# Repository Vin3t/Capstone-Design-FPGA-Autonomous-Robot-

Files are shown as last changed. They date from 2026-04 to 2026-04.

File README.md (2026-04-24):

Autonomous indoor service robots require real-time perception and navigation while maintaining low power consumption for extended operation. Conventional robotic platforms commonly rely on GPU-based systems, such as the NVIDIA Jetson Nano, which provide high computational performance but suffer from significant energy demands. This paper addresses the challenge of achieving efficient real-time processing under constrained power budgets by proposing an FPGA-based autonomous service robot architecture.

The proposed system integrates a Nexys A7 FPGA with a Raspberry Pi 4 to perform real-time perception, mapping, and navigation using LiDAR and stereo vision data. A discretized grid map is constructed on the FPGA, enabling efficient execution of the A* pathfinding algorithm and obstacle avoidance in dynamic indoor environments. Classical edge detection techniques are also implemented to enhance real-time environmental awareness.

The novelty of this work lies in the use of FPGA-based parallel processing to offload computationally intensive navigation tasks, an architecture designed to significantly improve energy efficiency compared to traditional GPU-based solutions. Additionally, the system provides a modular hardware–software co-design framework that supports real-time operation with reduced power consumption.

This work demonstrates a practical and scalable approach for autonomous robotics. Crucially, it establishes the methodological and physical foundation for future quantitative comparisons between FPGA and GPU architectures in mobile robotic applications, with implications for healthcare logistics, office automation, and indoor delivery systems.

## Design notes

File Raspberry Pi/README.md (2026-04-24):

# Raspberry Pi Subsystem

This directory contains the high-level software for the Raspberry Pi, which serves as the central user interface and communication hub for the autonomous service robot. The system handles manual motor control via a PlayStation 4 controller and provides a touchscreen graphical user interface for setting navigation goals and transmitting map data to the Nexys A7 FPGA.

## File Overview

* **`ps4_motor_control.py`**: A manual drive script that uses the Pygame library to read inputs from a connected PS4 controller. It maps the joystick axes to motor speeds and sends CRC16-validated packet commands to a RoboClaw motor controller over UART.
* **`robot_gui.py`**: A Tkinter touchscreen application. It displays a 20x20 navigation grid, manages simulated LiDAR obstacle mapping, captures user goal inputs, and handles bidirectional UART communication with the FPGA for hardware-accelerated A* pathfinding.

## Hardware Requirements

* **Raspberry Pi**  + **Touchscreen display recommended**
* **PS4 DualShock Controller** (Connected via USB)
* **RoboClaw Motor Controller** (Address configured to `128`)
* **Nexys A7 FPGA** (Connected via UART for pathfinding)

## System Setup and Dependencies

Before executing the scripts, ensure the Raspberry Pi's hardware UART is enabled and the serial console is disabled. 

1. Open the Raspberry Pi configuration tool in the terminal:
   ```bash
   sudo raspi-config

2. Navigate to Interface Options -> Serial Port.

3. Select No when asked if a login shell should be accessible over serial.

4. Select Yes when asked if the hardware serial port should be enabled.

5. Reboot the Raspberry Pi.

## Python Dependencies
Install the required libraries using pip:
   '''bash
      pip install pygame pyserial pillow numpy

## Instructions
1. Manual PS4 Control (ps4_motor_control.py)
Ensure the PS4 controller is paired to the Raspberry Pi. The script maps the left and right vertical joystick axes to independent tank-drive motor speeds.

    ```bash
        python3 ps4_motor_control.py

Left Stick (Vertical): Controls Motor 1 (Forward/Backward)

Right Stick (Vertical): Controls Motor 2 (Forward/Backward)

PS Button: Exits the script and safely halts the motors.

2. Autonomous Navigation GUI (robot_gui.py)
Run the GUI within the Raspberry Pi desktop environment.

   python3 robot_gui.py

## GUI Workflow:

Load LiDAR: Generates a map of obstacles (currently simulated for testing purposes).

Set Goal: Tap an empty cell on the 20x20 grid to mark the destination.

SEND & RUN: Transmits the 404-byte payload to the FPGA.

Unlock: Once the FPGA reports a successful arrival (0xBB), the unlock button becomes active, allowing the user to release the cargo.

## FPGA UART Protocol Specification
The robot_gui.py script communicates with the Nexys A7 FPGA using a strict 404-byte UART packet operating at 115200 baud. The FPGA automatically triggers the A* search on the rising edge of the final received map byte.

Transmitted Packet (Raspberry Pi -> FPGA)

Byte Index          Description             Value Range
0                   Start Row               0 - 19
1                   Start Column            0 - 19
2                   Goal Row                0 - 19
3                   Goal Column             0 - 19
4 to 403            Obstacle Map (Row)      0x00 (Free), 0x01 (Obstacle)

Status Replies (FPGA -> Raspberry Pi)
The GUI runs a background thread that polls for 1-byte status updates from the FPGA:

Byte Received           Meaning             System Action
0xAA                    Path Found          Updates the GUI status; motors engage.
0xFF                    No Path Exists      Prompts the user to replan the goal.
0xBB                    Arrived at Target   Navigation completes; enables the delivery lock release.

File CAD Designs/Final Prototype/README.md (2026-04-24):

Pololu: 37d gearmotor-50-70-encoder used as a reference for the motor mounting design ().
Pololu: Pololu wheels 90x10mm ().
Pololu: Motor Shaft mount (connects to the pololu wheel) [].

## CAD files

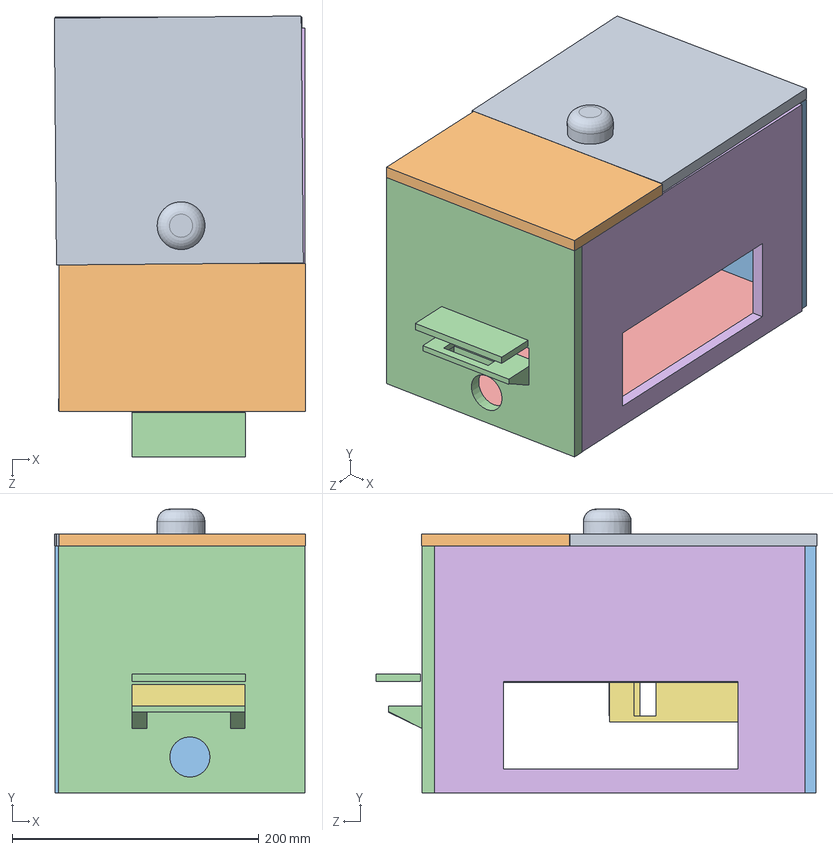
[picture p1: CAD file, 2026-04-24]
CAD Designs/Initial Prototype/robot_assem.SLDASM
203.6 x 229.9 x 357.3 mm
robot_middle_panel
robot_side_parts
robot_base
robot_front_panel
robot_back_panel
robot_lidar_panel
robot_top_hatch

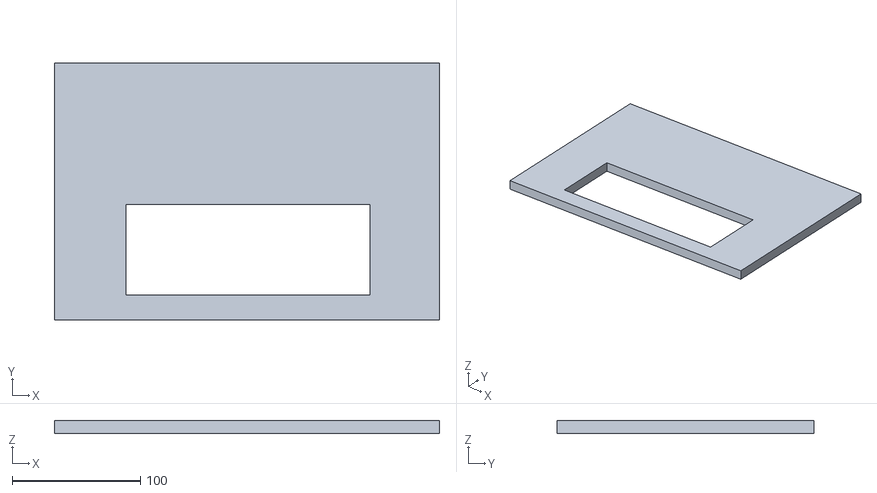
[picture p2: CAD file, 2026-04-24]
CAD Designs/Final Prototype/robot_side_partsv2.STL
300.0 x 200.0 x 10.0

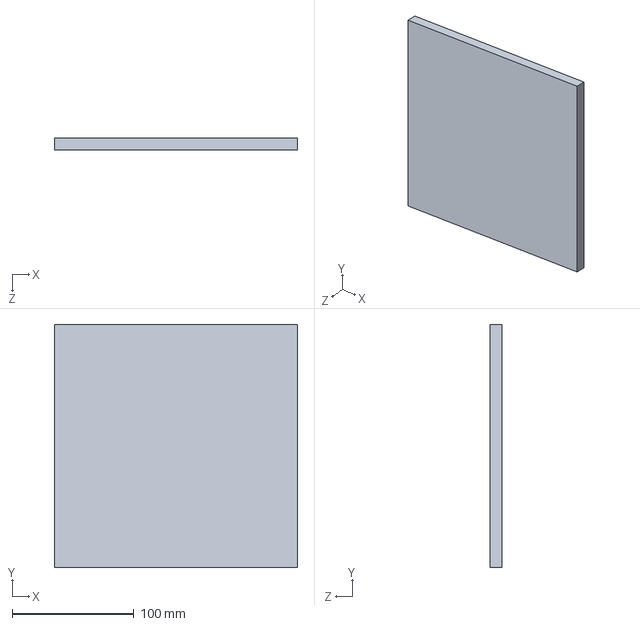
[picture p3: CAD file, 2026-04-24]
CAD Designs/Initial Prototype/robot_back_panel.SLDPRT
200.0 x 200.0 x 10.0 mm

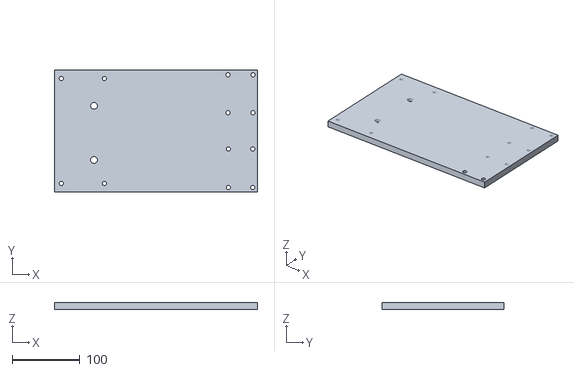
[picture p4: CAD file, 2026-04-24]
CAD Designs/Final Prototype/robot_basev2.STL
300.0 x 180.0 x 10.0

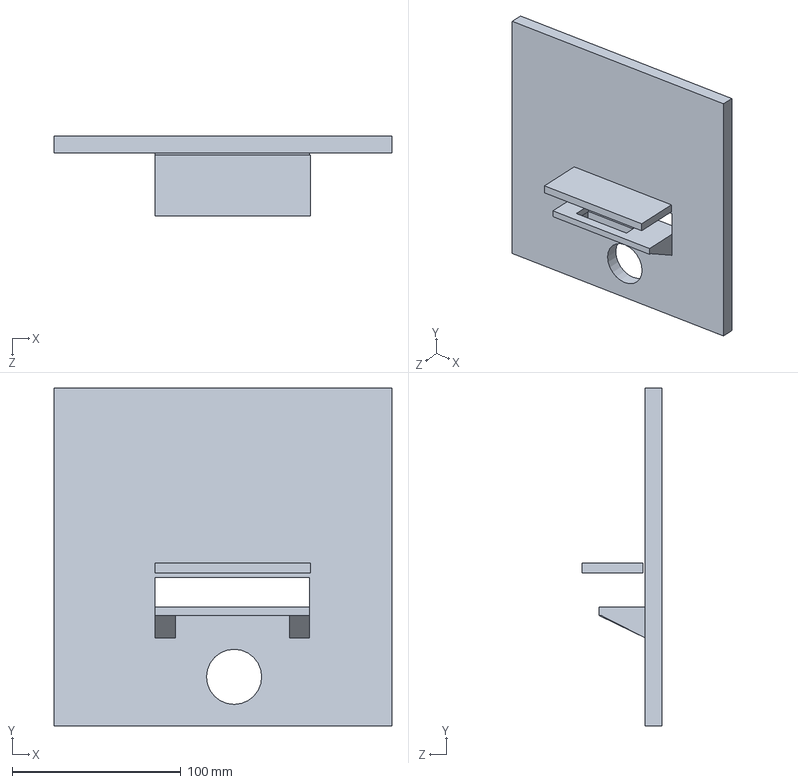
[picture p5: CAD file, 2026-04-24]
CAD Designs/Initial Prototype/robot_front_panel.SLDPRT
200.0 x 200.0 x 47.2 mm

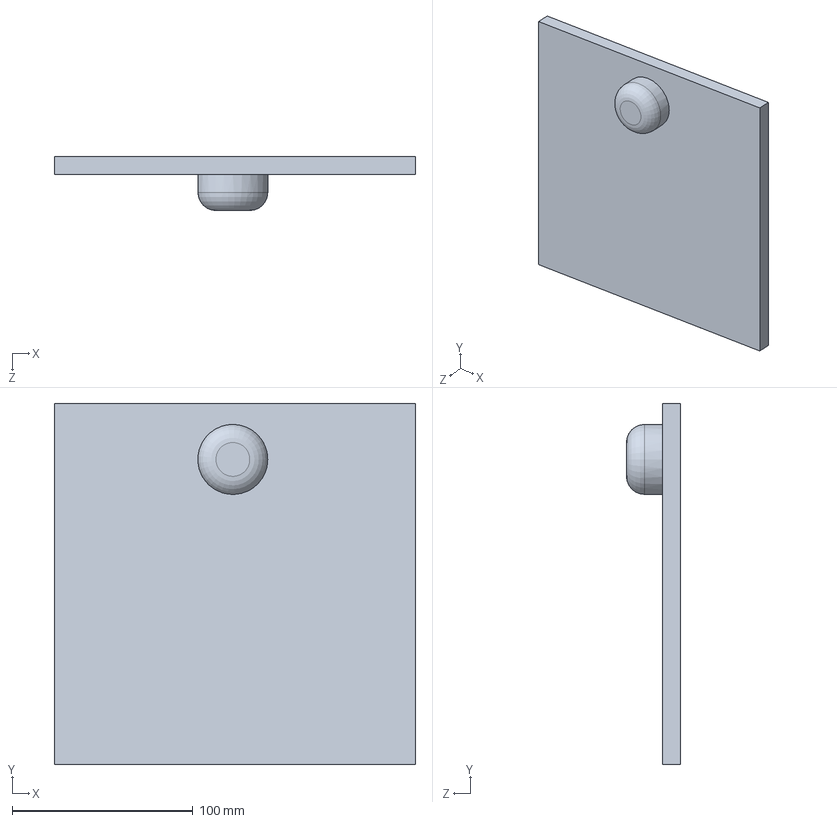
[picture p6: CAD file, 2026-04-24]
CAD Designs/Initial Prototype/robot_top_hatch.SLDPRT
200.0 x 200.0 x 30.0 mm

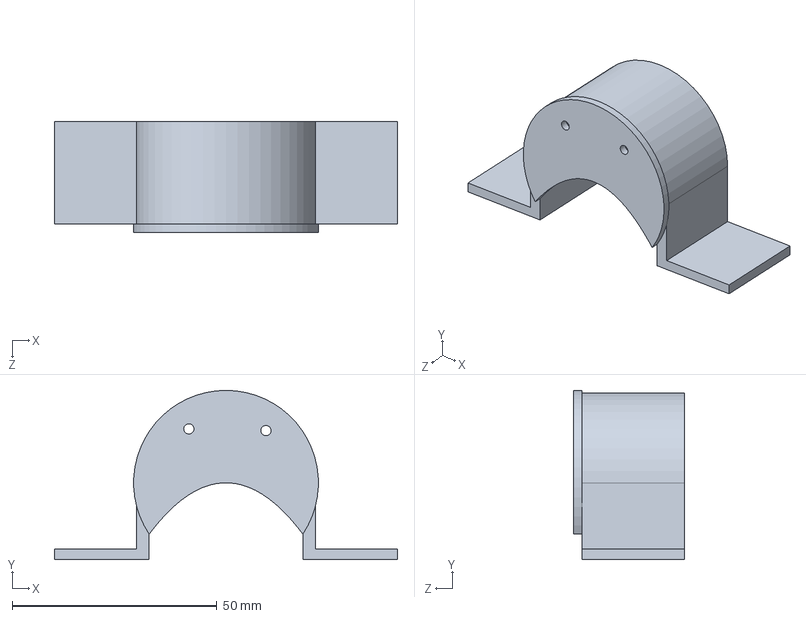
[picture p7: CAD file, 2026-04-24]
CAD Designs/Final Prototype/motor_mount capstone v1.SLDPRT
83.7 x 41.3 x 27.0 mm

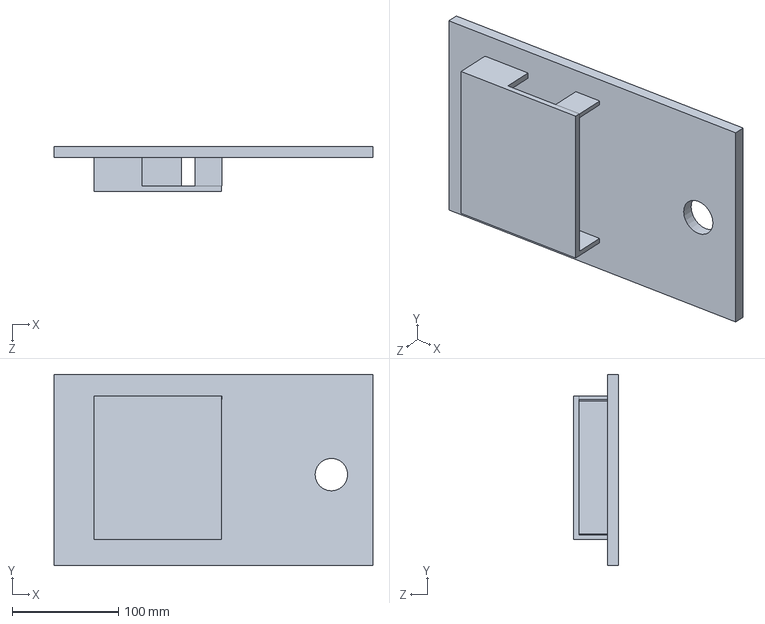
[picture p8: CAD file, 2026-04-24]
CAD Designs/Initial Prototype/robot_middle_panel.SLDPRT
300.0 x 180.0 x 42.0 mm

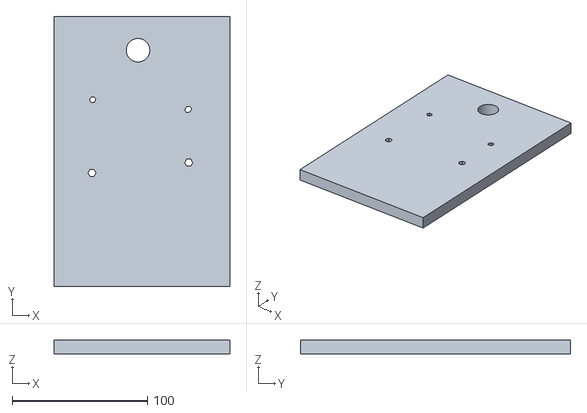
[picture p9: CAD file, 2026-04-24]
CAD Designs/Final Prototype/robot_lidar_panelv3.STL
130.0 x 200.0 x 10.0

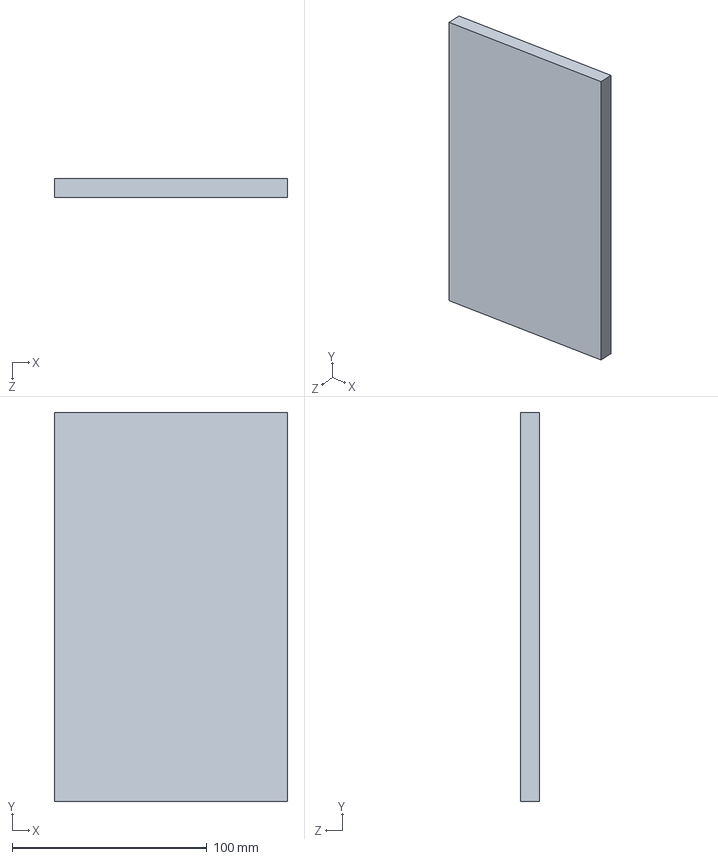
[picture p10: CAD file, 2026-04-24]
CAD Designs/Initial Prototype/robot_lidar_panel.SLDPRT
120.0 x 200.0 x 10.0 mm

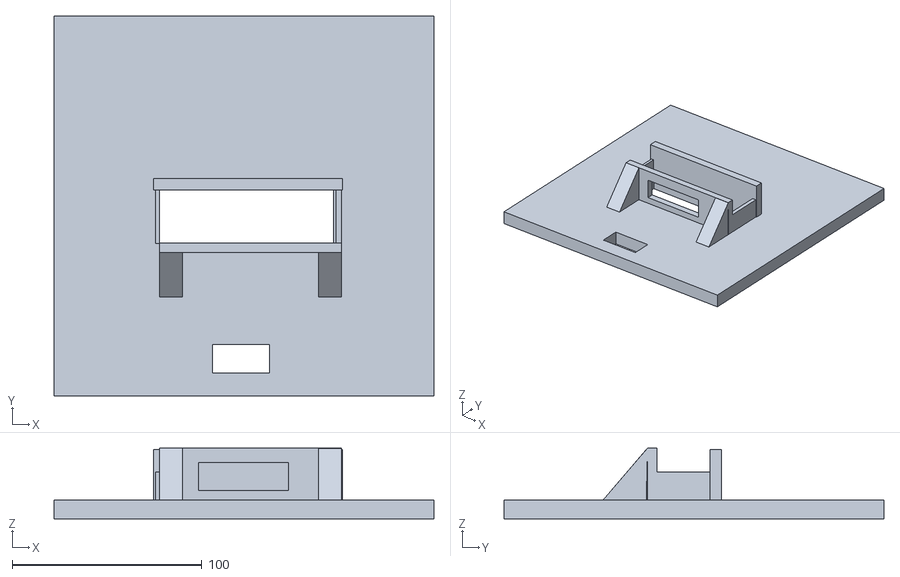
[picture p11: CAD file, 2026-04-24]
CAD Designs/Final Prototype/robot_front_panelv2.STL
200.0 x 200.0 x 37.2

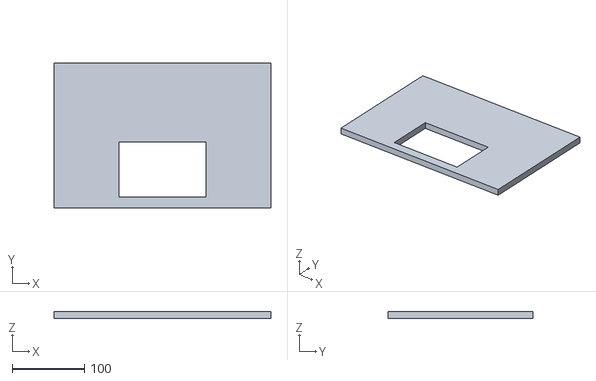
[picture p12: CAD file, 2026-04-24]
CAD Designs/Initial Prototype/robot_led_side_pannel.STL
300.0 x 200.0 x 10.0

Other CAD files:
CAD Designs/Final Prototype/robot_led_side_pannel.SLDPRT
CAD Designs/Initial Prototype/robot_side_parts.SLDPRT
CAD Designs/Final Prototype/robot_back_panelv2.STL
CAD Designs/Final Prototype/robot_middle_panelv2.STL
CAD Designs/Initial Prototype/robot_base.SLDPRT
CAD Designs/Initial Prototype/robot_middle_panel.STL
CAD Designs/Initial Prototype/robot_top_hatch.STL

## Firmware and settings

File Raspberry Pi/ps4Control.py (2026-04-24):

import pygame
import serial
import time

# Serial setup
ser = serial.Serial("/dev/serial0", 38400, timeout=0.1)
addr = 128 # RoboClaw address

# CRC16 function

def crc16(data):
	crc = 0
	for byte in data:
		crc ^= (byte << 8)
		for _ in range(8):
			if crc & 0x8000:
				crc = (crc << 1) ^ 0x1021
			else:
				crc <<= 1
			crc &= 0xFFFF
	return crc

# Send Packet command
def command(cmd, val):
	data = [addr, cmd, val]
	crc = crc16(data)
	packet = data + [crc >> 8, crc & 0xFF]
	ser.write(bytes(packet))

# Map joystick value (-1 to 1) to motor speed (0-127)
def stick_to_speed(value):
	return int(max(0, min(127, abs(int(value * 127)))))

# Motor commands
M1_FORWARD = 0
M1_BACKWARD = 1
M2_FORWARD = 4
M2_BACKWARD = 5

# Pygame setup
pygame.init()
pygame.joystick.init()

if pygame.joystick.get_count() == 0:
	print("No controller detected")
	exit()

joystick = pygame.joystick.Joystick(0)
joystick.init()
print(f"PS4 Controller Conneced: {joystick.get_name()}")

try:
	running = True
	while running:
		pygame.event.pump()

		# Left stick vertical
		left_axis = -joystick.get_axis(4)
		# Right stick vertical
		right_axis = -joystick.get_axis(1)

		left_speed = stick_to_speed(left_axis)
		right_speed = stick_to_speed(right_axis)

		if left_axis >= 0:
			command(M1_FORWARD, left_speed)
		else:
			command(M1_BACKWARD, left_speed)

		if right_axis >= 0:
			command(M2_FORWARD, right_speed)
		else:
			command(M2_BACKWARD, right_speed)

		# PS button to exit
		if joystick.get_button(9):
			running = False

		time.sleep(0.05)

finally:
	# Stop motors on exit
	command(M1_FORWARD, 0)
	command(M2_FORWARD, 0)
	ser.close()
	pygame.quit()
	print("EXIT")
	

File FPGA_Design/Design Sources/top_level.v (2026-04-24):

`timescale 1ns / 1ps
//     The Raspberry Pi should not talk to the motor controller.
//     RPi -> UART -> FPGA -> PWM/DIR ->  Roboclaw motor controller
//     go_pulse now asserted automatically when map load completes
// -----------------------------------------------------------------------
// UART protocol from Raspberry Pi (must match rpi_sender.py):
//   Byte 0        : start_row  
//   Byte 1        : start_col  
//   Byte 2        : goal_row   
//   Byte 3        : goal_col   
//   Bytes 4       : obstacle map, row-major (0x00=free, 0x01=obstacle)
//
// External pin connections:
//   UART_TXD_IN  <- RPi GPIO14 TX (USB-to-UART bridge or direct 3.3V GPIO)
//   BTNC         -> Start A* search after map loaded
//   CPU_RESETN   -> Active-low reset
//   E_STOP_PIN   <- Physical E-stop switch (active HIGH)
//   PWM_L        -> Roboclaw S1 (left  motor PWM)
//   PWM_R        -> Roboclaw S2 (right motor PWM)
//   VGA_*        -> VGA connector
// -----------------------------------------------------------------------

module top_level #(
    parameter CLK_FREQ  = 100_000_000,
    parameter BAUD_RATE = 115_200
    )(
    input wire CLK100MHZ,
    input wire CPU_RESETN,
 
    // UART from Raspberry Pi (RPi TX ? FPGA RX)
    input wire UART_TXD_IN,
    
    // UART back to Raspberry Pi (FPGA TX ? RPi RX)
    // Connect to RPi GPIO15 (UART0 RX, pin 10)
    // Status bytes sent:  
    // 0xAA = path found / navigating
    // 0xFF = no path exists
    // 0xBB = navigation complete (arrived)
    output wire UART_RXD_OUT,
 
    // Motor controller outputs - FPGA drives Roboclaw directly
    output wire PWM_L,
    output wire PWM_R
);
 
    wire rst = ~CPU_RESETN;
 
    //  UART RX
    wire [7:0] uart_byte;
    wire uart_valid;
 
    uart_rx #(
        .CLK_FREQ(CLK_FREQ),
        .BAUD_RATE(BAUD_RATE)
    ) u_uart (
        .clk(CLK100MHZ),
        .rst(rst),
        .rx(UART_TXD_IN),
        .data_out(uart_byte),
        .data_valid(uart_valid)
    );
 
     //  UART loader FSM
    //  Receives: start_row, start_col, goal_row, goal_col, then 400 map bytes
    //  Automatically pulses go_pulse when the full map has been received 
    localparam L_START_ROW = 3'd0;
    localparam L_START_COL = 3'd1;
    localparam L_GOAL_ROW = 3'd2;
    localparam L_GOAL_COL = 3'd3;
    localparam L_MAP = 3'd4;
 
    reg [2:0] loader_state = L_START_ROW;
    reg [8:0] start_cell_r = 0;
    reg [8:0] goal_cell_r = 0;
    reg [7:0] tmp_row = 0;
    reg load_start = 0;
    reg map_uart_valid = 0;
    reg [7:0]  map_uart_byte = 0;
 
    always @(posedge CLK100MHZ) begin
        load_start <= 1'b0;
        map_uart_valid <= 1'b0;
 
        if (rst) begin
            loader_state <= L_START_ROW;
        end else if (uart_valid) begin
            case (loader_state)
                L_START_ROW: begin
                    tmp_row <= uart_byte;
                    loader_state <= L_START_COL;
                end
                L_START_COL: begin
                    start_cell_r <= tmp_row * 20 + uart_byte;
                    loader_state <= L_GOAL_ROW;
                end
                L_GOAL_ROW: begin
                    tmp_row <= uart_byte;
                    loader_state <= L_GOAL_COL;
                end
                L_GOAL_COL: begin
                    goal_cell_r <= tmp_row * 20 + uart_byte;
                    load_start <= 1'b1;
                    loader_state <= L_MAP;
                end
                L_MAP: begin
                    map_uart_byte <= uart_byte;
                    map_uart_valid <= 1'b1;
                end
                default: ;
            endcase
        end
    end
 
    //  Grid memory
    wire load_done;
    wire [8:0] grid_addr_a;
    wire grid_obs_a;
 
    grid_memory #(.ROWS(20), .COLS(20)) u_grid (
        .clk(CLK100MHZ),
        .rst(rst),
        .load_start(load_start),
        .uart_data(map_uart_byte),
        .uart_valid(map_uart_valid),
        .load_done(load_done),
        .cell_addr_a(grid_addr_a),
        .cell_data_a(grid_obs_a),
        .cell_addr_b(9'd0),
        .cell_data_b()
    );
 
    //  go_pulse - fires automatically when map load completes.
    //  A single-cycle pulse is generated on the rising edge of load_done.
    reg map_load_started = 1'b0;
    always @(posedge CLK100MHZ) begin
        if (rst) map_load_started <= 1'b0;
        else if (load_start) map_load_started <= 1'b1;
    end
    
    reg load_done_prev = 1'b0;
    always @(posedge CLK100MHZ) load_done_prev <= load_done;
    
    wire go_pulse = load_done & ~load_done_prev & map_load_started;
 
    //  A* core
    wire astar_done;
    wire astar_no_path;
    wire astar_searching;
    wire [8:0] cf_rd_addr;
    wire [8:0] cf_rd_data;
 
    astar_core #(.ROWS(20), .COLS(20)) u_astar (
        .clk(CLK100MHZ),
        .rst(rst),
        .go(go_pulse),
        .start_cell(start_cell_r),
        .goal_cell(goal_cell_r),
        .grid_addr(grid_addr_a),
        .grid_obstacle(grid_obs_a),
        .done(astar_done),
        .no_path(astar_no_path),
        .searching(astar_searching),
        .cf_rd_addr(cf_rd_addr),
        .cf_rd_data(cf_rd_data)
    );
 
    //  Path tracer
    //  Walks came_from RAM from goal back to start; emits path_vis bitmap
    //  and signals trace_done when the ordered waypoint list is ready.
    wire [399:0] path_vis;
    wire trace_done;
 
    path_tracer #(.ROWS(20), .COLS(20)) u_tracer (
        .clk(CLK100MHZ),
        .rst(rst),
        .start_trace(astar_done),
        .goal_cell(goal_cell_r),
        .start_cell(start_cell_r),
        .cf_addr(cf_rd_addr),
        .cf_data(cf_rd_data),
        .path_valid(path_vis),
        .trace_done(trace_done)
    );
 
    //  Nav FSM
    //  Reads ordered waypoints from path_tracer and issues speed commands.
    //  wp_data / path_length are stubs - extend path_tracer to export an
    //  ordered waypoint RAM and length counter when ready.
    wire [8:0] wp_data = 9'd0;   // stub: replace with path_tracer waypoint RAM output
    wire [8:0] wp_addr;
    wire [7:0] path_length = 8'd0;  // stub: replace with path_tracer path_length output
    wire nav_done;
    wire nav_busy;
    wire signed [7:0] speed_l_w;
    wire signed [7:0] speed_r_w;
 
    nav_fsm #(
        .COLS(20),
        .DRIVE_TICKS(100_000_000),
        .TURN_TICKS(50_000_000)
    ) u_nav (
        .clk(CLK100MHZ),
        .rst(rst),
        .path_ready(trace_done),
        .wp_data(wp_data),
        .wp_addr(wp_addr),
        .path_length(path_length),
        .speed_l(speed_l_w),
        .speed_r(speed_r_w),
        .nav_done(nav_done),
        .nav_busy(nav_busy)
    );
 
    //  PWM motor controller - Should change so that it directly drives Roboclaw from FPGA
    pwm_motor_ctrl u_pwm (
        .clk(CLK100MHZ),
        .rst(rst),
        .speed_l(speed_l_w),
        .speed_r(speed_r_w),
        .pwm_l(PWM_L),
        .pwm_r(PWM_R)
    );
    
    //  Status arbiter - converts FPGA events to 1-byte UART replies
    //
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

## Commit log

2026-04-24 Add files via upload
    File for the robot top hatch version 1
    [robot_top_hatch.STL]
2026-04-24 Design sources for grid memory, path tracer, pwm motor ctrl, and uart. Final simulation file for uart
2026-04-24 Changes to folder structure
    [robot_assem.SLDASM, robot_back_panel.SLDPRT, robot_base.SLDPRT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]
2026-04-24 Contents for raspberry pi portion of this project
2026-04-24 Raspberry pi portion of this project
2026-04-24 README.md for Raspberry pi
2026-04-24 Raspberry pi README.md reformatting
2026-04-24 Update formatting in Raspberry Pi README
    Fix formatting for code blocks and instructions in README.
2026-04-24 Fix formatting in Raspberry Pi README
    Fixed formatting issues in the README file.
2026-04-24 Fix mispelling README.md in CAD Design folder
